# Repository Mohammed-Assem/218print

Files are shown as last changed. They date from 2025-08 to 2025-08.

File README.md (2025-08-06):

## 218print

218print is a simple bedslinger 3d printer designed to be as cheap as possible. I wanted to do this project because I don't know about 3d printers and I hoped to have one, so it was like a challenge to build it. I used3d printed parts in the motion of z-axis to be cheaper than universal plates.

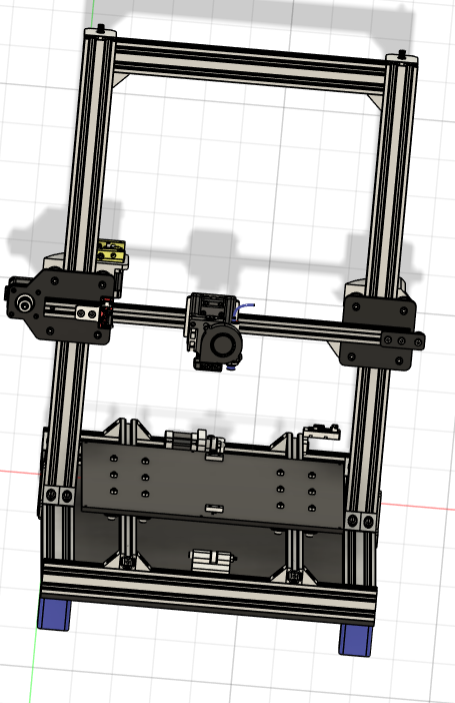
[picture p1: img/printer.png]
3D desgin
  
  z_axis
  y_axis

  this is my BOM file: 
  https://docs.google.com/spreadsheets/d/1YMHhHpfrs8DgpCIIZugQnNaR5hrPWCmoNuoNPDEoR1U/edit?usp=sharing

# Bill of Materials (BOM)

| Qty | Component | Price (EGP) | Total Price | Price (USD) | Link |
|-----|---|---|---|---|---|
| 1 | BIGTREETECH SKR MINI E3 V3.0 32 Bit Control Board | 3300 | 3300 | 68.04 | [Link](https://fluxelectronix.com/shop/bigtreetech-skr-mini-e3-v3-0-32-bit-control-board/) |
| 1 | Proximity Sensor - LJ12A3-4-Z-BX | £120.00 | £120.00 | 2.47 | [Link](https://lancer3d.com/product/proximity-sensor-lj12a3-4-z-bx/) |
| 2 | Mechanical End Stop Module | £25.00 | £50.00 | 1.03 | [Link](https://www.ram-e-shop.com/shop/kit-3d-1003-3d-printer-mechanical-end-stop-switch-module-for-ramps-sku-3d1003-7267) |
| 2 | Fan 4040 -- 24v | £35.00 | £70.00 | 1.44 | [Link](https://lancer3d.com/product/fan-4040-12v/) |
| 1 | 5015 Blower Fan -- 24v | £60.00 | £60.00 | 1.24 | [Link](https://lancer3d.com/product/5015-turbo-blower-fan-24-v-50x50x15mm/) |
| 1 | E3d V6 Hotend Full Kit | £325.00 | £325.00 | 6.70 | [Link](https://fluxelectronix.com/shop/e3d-v6-j-head-hotend-1-75mm-extruder-nozzle-0-4mm) |
| 1 | 214x214 3mm Aluminium | 290 | 290 | 5.98 | [Link](https://fluxelectronix.com/shop/3d-printer-mk3-aluminum-heatbed-214x214x3mm-dual-supply/) |
| 1 | Power Supply SMPS 20A 24V | £1,250.00 | £1,250.00 | 25.77 | [Link](https://fluxelectronix.com/shop/power-supply-smps-480w-24v-20a-hq/) |
| 1 | AC Inlet Power Socket with Fuse Holder | £15.00 | £15.00 | 0.31 | [Link](https://fluxelectronix.com/shop/panel-mount-ac-inlet-power-socket-with-fuse/) |
| 1 | Power Supply Cable | £30.00 | £30.00 | 0.62 | [Link](https://fluxelectronix.com/shop/ac-power-cord-with-iec-c13-connector/) |
| 1 | Zip Ties (100 pcs) | - | - | 0 | Already owned |
| 1 | NTC 100K Ohm Thermistor | £30.00 | £30.00 | 0.62 | [Link](https://fluxelectronix.com/shop/100k-ohm-ntc-thermistors-temperature-sensor-with-cable-for-3d-printer-2pin-dupont-head/) |
| 1 | 32GB Micro SD Memory Card HC10 | 375 | 375 | 7.73 | [Link](https://www.ram-e-shop.com/ar/shop/micro-sd-32gb-krt-mymwry-mykrw-32-jyj-hc10-6298) |
| 1 | Raspberry Pi Zero 2 W | 2100 | 2100 | 43.30 | [Link](https://www.ram-e-shop.com/ar/shop/raspberry-pi-zero-2w-raspberry-pi-zero-2-w-9256) |
| - | Mechanical | - | - | 0 | - |
| 5 | 2040 V-slot (34cm) | 300 | £1,500.00 | 30.93 | [Link](https://fluxelectronix.com/shop/2040-v-slot-aluminum-profile-extrusion-1m-black-anodized/) |
| 2 | 2040 V-slot (42cm) | - | - | 0 | - |
| 1 | 2040 V-slot (64cm) | - | - | 0 | - |
| 2 | 2040 V-slot (60cm) | - | - | 0 | - |
| 2.5 | 2020 V-slot (46cm) | 160 | £400.00 | 8.25 | [Link](https://www.juthour-tech.com/en/v-slot-20x20-linear-rail) |
| 1 | 2020 V-slot (68cm) | - | - | 0 | - |
| 22 | 2040 Corner Bracket | 20 | £440.00 | 9.07 | [Link](https://lancer3d.com/product/corner-bracket-for-20x40/) |
| 4 | Steel Flat T-Joint Plate | 25 | £100.00 | 2.06 | [Link](https://lancer3d.com/product/t-corner-mount-bracket/) |
| 2 | Corner Bracket 20x20 | 15 | £30.00 | 0.62 | [Link](https://lancer3d.com/product/corner-angle-20x20/) |
| 23 | Solid V-Wheel | 45 | £1,035.00 | 21.34 | [Link](https://fluxelectronix.com/shop/delrin-v-wheel/) |
| 3 | GT2 Timing Belt (X-axis, 1.5m) | 45 | £135.00 | 2.78 | [Link](https://ampere-electronics.com/product/gt2-open-belt-6mm-wide-pu-with-steel-core-1-meter-black/) |
| 1 | GT2 Timing Belt (Y-axis, 1.5m) | - | - | 0 | - |
| 90 | M5 Slide T-Nuts | 3.5 | £315.00 | 6.49 | [Link](https://ampere-electronics.com/product/m5-sliding-tee-nut-for-2020-profile/) |
| 2 | GT2 Pulley 20T 5mm | 30 | £60.00 | 1.24 | [Link](https://fluxelectronix.com/shop/20teeth-gt2-timing-belt-pulley-5mm-bore/) |
| 3 | GT2 Toothless Pulley 5mm | 35 | £105.00 | 2.16 | [Link](https://fluxelectronix.com/shop/toothless-gt2-idler-pulley-5mm-bore/) |
| 4 | Leveling Screw (M3x40) | 12.5 | £50.00 | 1.03 | [Link](https://ampere-electronics.com/product/leveling-kit-m3-screw-spring-knob-for-3d-printer/) |
| 5 | Nema17 Stepper Motor 17HS4401S – 38mm | £450.00 | £2,250.00 | 46.39 | [Link](https://fluxelectronix.com/shop/nema17-stepper-motor-17hs4401s-38mm/) |
| 1 | MK8 Remote Extruder Kit | 105 | £105.00 | 2.16 | [Link](https://ampere-electronics.com/product/mk8-remote-extruder-aluminum-frame-clamp-block-diy/) |
| 2 | Flexible Coupler 5x8mm | 40 | £80.00 | 1.65 | [Link](https://ampere-electronics.com/product/5x8mm-flexible-shaft-coupler/) |
| 1 | TR8x8 Lead Screw – 1200mm | 310 | £310.00 | 6.39 | [Link](https://ampere-electronics.com/product/tr8x8-acme-lead-screw-1200mm/) |
| 2 | TR8x8 Lead Screw Copper Nut | 30 | £60.00 | 1.24 | [Link](https://fluxelectronix.com/shop/tr8x8-acme-leadscrew-copper-nut/) |
| 10 | M5 Drop-in T-Nut | 3 | £30.00 | 0.62 | [Link](https://ampere-electronics.com/product/m5-drop-in-tee-nut-for-2020-aluminum-profile/) |
| 1 | M3x10mm Screw | - | - | 0 | Already owned |
| 1 | M3x15mm Screw | - | - | 0 | Already owned |
| 1 | M3x20mm Screw | - | - | 0 | Already owned |
| 1 | M3x25mm Screw | - | - | 0 | Already owned |
| 1 | M3 Standard Nut | - | - | 0 | Already owned |
| 1 | M5 Flat Head Screw 10mm | - | - | 0 | Already owned |
| 1 | M5 Flat Head Screw 12mm–15mm | - | - | 0 | Already owned |
| 1 | M5 Flat Head Screw 25mm | - | - | 0 | Already owned |
| 1 | M5 Flat Head Screw 30mm | - | - | 0 | Already owned |
| 1 | M5 Flat Head Screw 35mm | - | - | 0 | Already owned |
| 1 | M5 Flat Head Screw 40mm | - | - | 0 | Already owned |
| 12 | 6mm M5 Eccentric Spacer | 5 | £60.00 | 1.24 | [Link](https://ampere-electronics.com/product/aluminum-spacer-5-1x10x6mm/) |
| 10 | 3mm M5 Spacer | 3 | £30.00 | 0.62 | [Link](https://ampere-electronics.com/product/aluminum-spacer-5-1x10x3mm/) |
| 2 | 6mm M5 Spacer | 5 | £10.00 | 0.21 | [Link](https://ampere-electronics.com/product/aluminum-spacer-5-1x10x6mm/) |
| 20 | 9mm M5 Spacer | 7 | £140.00 | 2.89 | [Link](https://ampere-electronics.com/product/aluminum-spacer-5-1x10x9mm/) |
| 350g | 3D Printing Filament (EGP 4/g) | 3 | £1,050.00 | 21.65 | Will print in Flux |
| 1 | 1/4 Acrylic Sheet(0.5 m square) | 650 | £650.00 | 13.40 | - |

---

**Total Price:**  
- **EGP:** 10,257  
- **Total EGP:** £16,960.00  
- **USD:** $349.69

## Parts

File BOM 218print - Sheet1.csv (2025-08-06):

Quantity | Component | Price(EGP) | Total Price | price in usd | links local
1 | BIGTREETECH SKR MINI E3 V3.0 32 Bit Control Board | 3300 | 3300 | 68.04123711 | https://fluxelectronix.com/shop/bigtreetech-skr-mini-e3-v3-0-32-bit-control-board/
1 | Proximity-Sensor- LJ12A3-4-Z-BX | £120.00 | £120.00 | 2.474226804 | https://lancer3d.com/product/proximity-sensor-lj12a3-4-z-bx/
2 | Mechincal End Stop Module | £25.00 | £50.00 | 1.030927835 | https://www.ram-e-shop.com/shop/kit-3d-1003-3d-printer-mechanical-end-stop-switch-module-for-ramps-sku-3d1003-7267
2 | Fan 4040 -- 24v | £35.00 | £70.00 | 1.443298969 | https://lancer3d.com/product/fan-4040-12v/
1 | 5015 Blower fan -- 24v | £60.00 | £60.00 | 1.237113402 | https://lancer3d.com/product/5015-turbo-blower-fan-24-v-50x50x15mm/
1 | E3d V6 Hotend full kit | £325.00 | £325.00 | 6.701030928 | https://fluxelectronix.com/shop/e3d-v6-j-head-hotend-1-75mm-extruder-nozzle-0-4mm
1 | 300x300mm Silicone Heatbed, 220Vac, 600W | 290 | 290 | 5.979381443 | https://fluxelectronix.com/shop/3d-printer-mk3-aluminum-heatbed-214x214x3mm-dual-supply/
1 | Power Supply SMPS 20A 24V | £1,250.00 | £1,250.00 | 25.77319588 | https://fluxelectronix.com/shop/power-supply-smps-480w-24v-20a-hq/
1 | AC Inlet power socket with fuse holder | £15.00 | £15.00 | 0.3092783505 | https://fluxelectronix.com/shop/panel-mount-ac-inlet-power-socket-with-fuse/
1 | Power Supply cable | £30.00 | £30.00 | 0.618556701 | https://fluxelectronix.com/shop/ac-power-cord-with-iec-c13-connector/
1 | zip ties 100 |  |  | 0 | already owned
1 | NTC 100K ohm thermistor for heated bed | £30.00 | £30.00 | 0.618556701 | https://fluxelectronix.com/shop/100k-ohm-ntc-thermistors-temperature-sensor-with-cable-for-3d-printer-2pin-dupont-head/
1 | 32GB Micro SD Memory Card HC10 | 375 | 375 | 7.731958763 | https://www.ram-e-shop.com/ar/shop/micro-sd-32gb-krt-mymwry-mykrw-32-jyj-hc10-6298
1 | Raspberry Pi Zero 2 W | 2100 | 2100 | 43.29896907 | https://www.ram-e-shop.com/ar/shop/raspberry-pi-zero-2w-raspberry-pi-zero-2-w-9256
 | mechanical |  |  | 0
5 | 2040 V-slot aluminium profile 34cm (Frame) | 300 | £1,500.00 | £30.93 | https://fluxelectronix.com/shop/2040-v-slot-aluminum-profile-extrusion-1m-black-anodized/
 | 2 X 2040 V-slot aluminium profile 42cm (Frame) |  |  | 0
 | 1 X 2040 V-slot aluminium profile 64cm (Frame) |  |  | 0
 | 2 X 2040 V-slot aluminium profile 60cm (Frame) |  |  | 0
2.5 | 2020 V-slot aluminium profile 46cm (X-axis) | 160 | £400.00 | £8.25 | https://www.juthour-tech.com/en/v-slot-20x20-linear-rail
 | 2020 V-slot aluminium profile 68cm (Y-axis) |  |  | 0
22 | 2040 aluminum profile corner bracket | 20 | £440.00 | £9.07 | https://lancer3d.com/product/corner-bracket-for-20x40/
4 | Steel flat T-joint plate | 25 | £100.00 | £2.06 | https://lancer3d.com/product/t-corner-mount-bracket/
2 | corner bracket 20X20 | 15 | £30.00 | £0.62 | https://lancer3d.com/product/corner-angle-20x20/
23 | Solid V-wheel | 45 | £1,035.00 | £21.34 | https://fluxelectronix.com/shop/delrin-v-wheel/
3 | GT2 open timing 6mm belt for the X-axis (1.5 metre) | 45 | £135.00 | £2.78 | https://ampere-electronics.com/product/gt2-open-belt-6mm-wide-pu-with-steel-core-1-meter-black/
 | GT2 open timing 6mm belt for the Y-axis (1.5 metre) |  |  | 0
90 | M5 slide T_nuts | 3.5 | £315.00 | £6.49 | https://ampere-electronics.com/product/m5-sliding-tee-nut-for-2020-profile/
2 | GT2 20Teeth pulley for 6mm belt bore 5mm (5mm inner) | 30 | £60.00 | £1.24 | https://fluxelectronix.com/shop/20teeth-gt2-timing-belt-pulley-5mm-bore/
3 | GT2 Toothless pulley for 6mm belt bore 5mm (5mm inner) | 35 | £105.00 | £2.16 | https://fluxelectronix.com/shop/toothless-gt2-idler-pulley-5mm-bore/
4 | Leveling Screw (M3*40) | 12.5 | £50.00 | £1.03 | https://ampere-electronics.com/product/leveling-kit-m3-screw-spring-knob-for-3d-printer/
5 | Nema17 Stepper Motor 17HS4401S – 38mm | £450.00 | £2,250.00 | 46.39175258 | https://fluxelectronix.com/shop/nema17-stepper-motor-17hs4401s-38mm/
1 | MK8 Remote Extruder Kit | 105 | £105.00 | £2.16 | https://ampere-electronics.com/product/mk8-remote-extruder-aluminum-frame-clamp-block-diy/
2 | Flexible Coupler 5*8mm | 40 | £80.00 | £1.65 | https://ampere-electronics.com/product/5x8mm-flexible-shaft-coupler/
1 | TR8x8 Acme Lead Screw– 1200mm | 310 | £310.00 | £6.39 | https://ampere-electronics.com/product/tr8x8-acme-lead-screw-1200mm/
2 | TR8x8 Acme Leadscrew Copper Nut | 30 | £60.00 | £1.24 | https://fluxelectronix.com/shop/tr8x8-acme-leadscrew-copper-nut/
10 | M5 drop in T_nut | 3 | £30.00 | £0.62 | https://ampere-electronics.com/product/m5-drop-in-tee-nut-for-2020-aluminum-profile/
1 | M3x10mm screw |  |  | 0 | Already owned
1 | M3x15mm screw |  |  | 0
1 | M3 20mm screw |  |  | 0
1 | M3 25mm screw |  |  | 0
1 | M3 standard nut |  |  | 0
1 | M5--10mm flat head screw low profile |  |  | 0
1 | M5--12mm or 15mm flat head screw low profile |  |  | 0
1 | M5--25mm flat head screw low profile |  |  | 0
1 | M5--30mm flat head screw low profile |  |  | 0
1 | M5--35mm flat head screw low profile |  |  | 0
1 | M5--40mm flat head screw low profile |  |  | 0
12 | 6mm M5 Ecentric spacer for V-wheels | 5 | £60.00 | £1.24 | https://ampere-electronics.com/product/aluminum-spacer-5-1x10x6mm/
10 | 3mm M5 spacer | 3 | £30.00 | £0.62 | https://ampere-electronics.com/product/aluminum-spacer-5-1x10x3mm/
2 | 6mm M5 spacer | 5 | £10.00 | £0.21 | https://ampere-electronics.com/product/aluminum-spacer-5-1x10x6mm/
20 | 9mm M5 spacer | 7 | £140.00 | £2.89 | https://ampere-electronics.com/product/aluminum-spacer-5-1x10x9mm/
350 | 3d printing the gram of printing costs 4 EGP | 3 | £1,050.00 | £21.65 | I will print in flux electronics
1 | 1/4 acrlyic sheet | 650 | £650.00 | £13.40
total |  | 10257 | £16,960.00 | 349.6907216

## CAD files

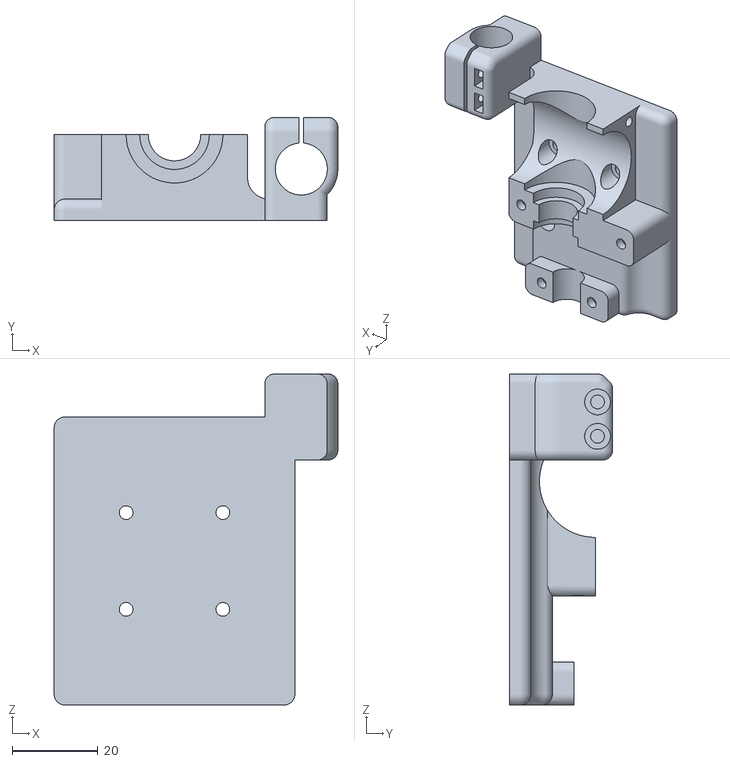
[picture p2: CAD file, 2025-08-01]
3D printed parts/STLs/Main_body_12mm_sensor.stl
66.0 x 24.0 x 77.0

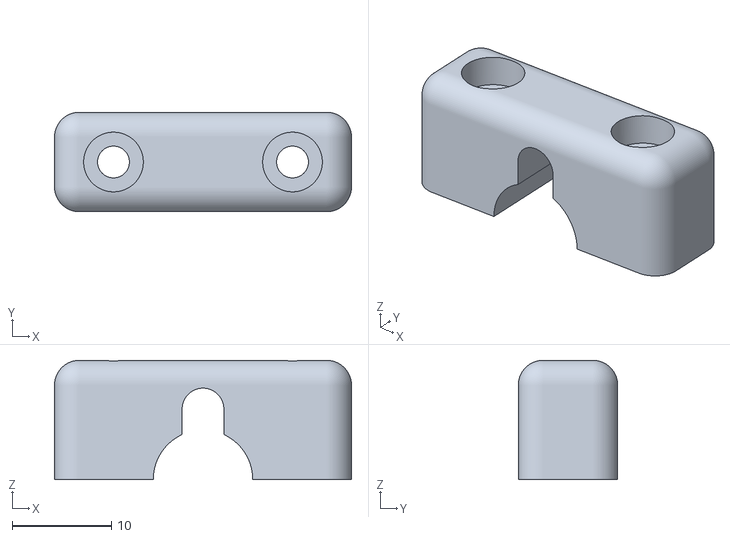
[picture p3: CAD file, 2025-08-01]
3D printed parts/STLs/Cable_clamp.stl
29.9 x 10.0 x 12.0

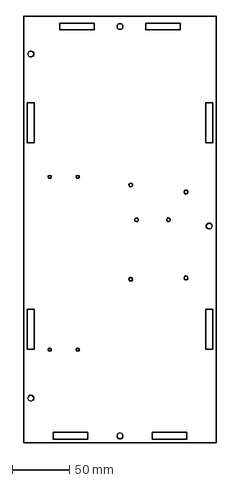
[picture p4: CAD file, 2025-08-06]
Acrylic sheets cut parts/DXFs/electronics base plate.dxf
168.0 x 373.1 mm

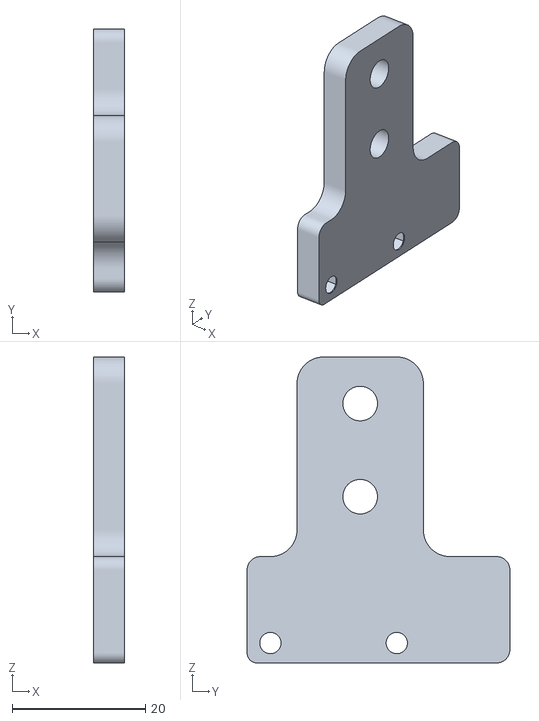
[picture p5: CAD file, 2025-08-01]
3D printed parts/STLs/X-axis endstop holder.stl
4.70 x 39.5 x 46.0

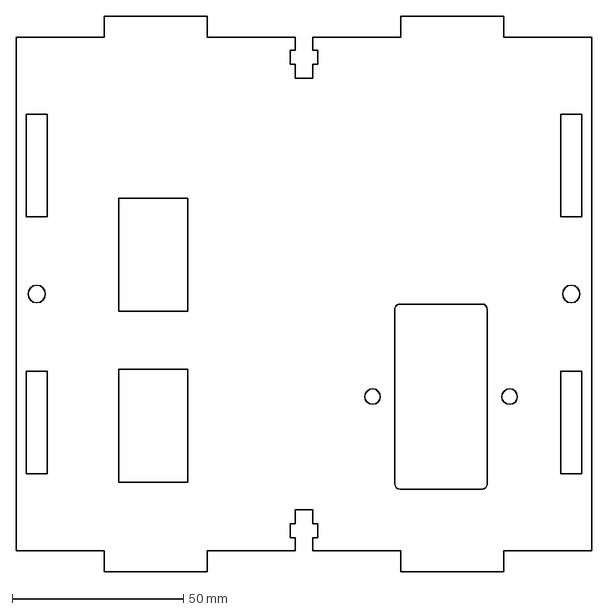
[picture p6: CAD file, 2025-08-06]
Acrylic sheets cut parts/DXFs/electronics back plate.dxf
168.0 x 162.0 mm

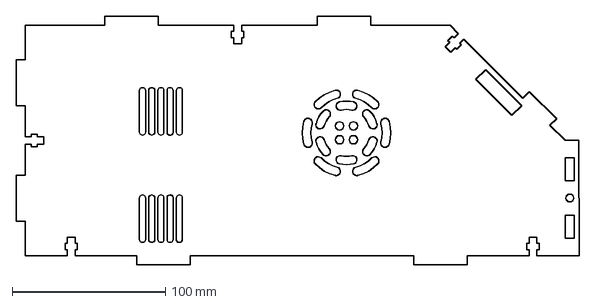
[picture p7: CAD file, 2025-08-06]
Acrylic sheets cut parts/DXFs/electronics left PSU plate.dxf
367.1 x 162.0 mm

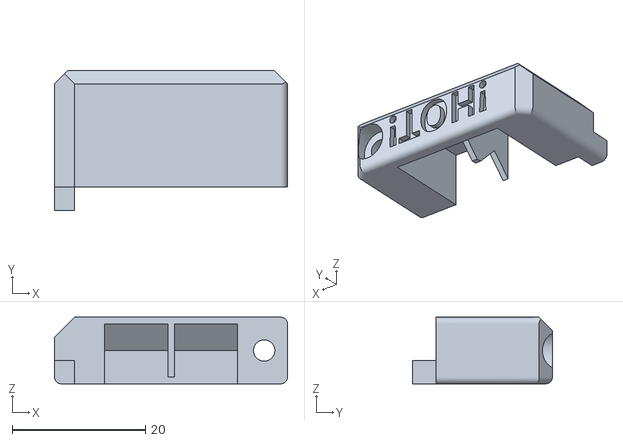
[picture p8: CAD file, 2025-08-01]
3D printed parts/STLs/Fan_duct v1.stl
35.0 x 21.0 x 10.0

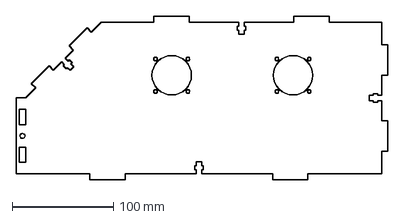
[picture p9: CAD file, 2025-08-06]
Acrylic sheets cut parts/DXFs/electronics right fans plate.dxf
367.1 x 162.0 mm

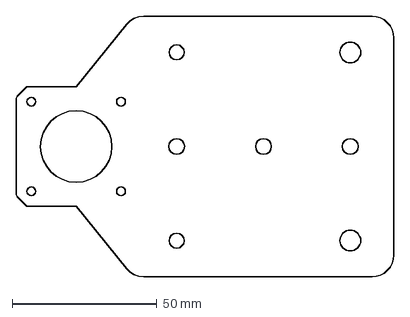
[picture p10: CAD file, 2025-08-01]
Acrylic sheets cut parts/DXFs/X-axis motor left plate.dxf
130.4 x 90.0 mm

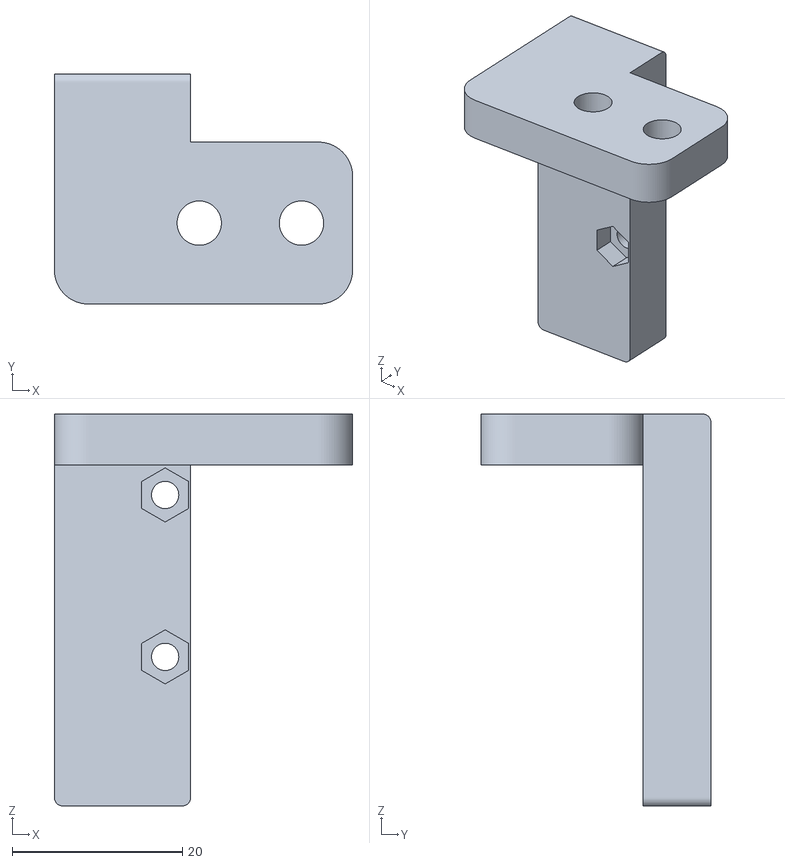
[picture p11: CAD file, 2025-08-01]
3D printed parts/STLs/Y-axis endstop holder.stl
35.0 x 27.0 x 46.0

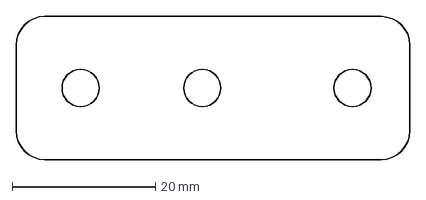
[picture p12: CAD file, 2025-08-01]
Acrylic sheets cut parts/DXFs/X-axis idler pulley plate.dxf
55.0 x 20.0 mm

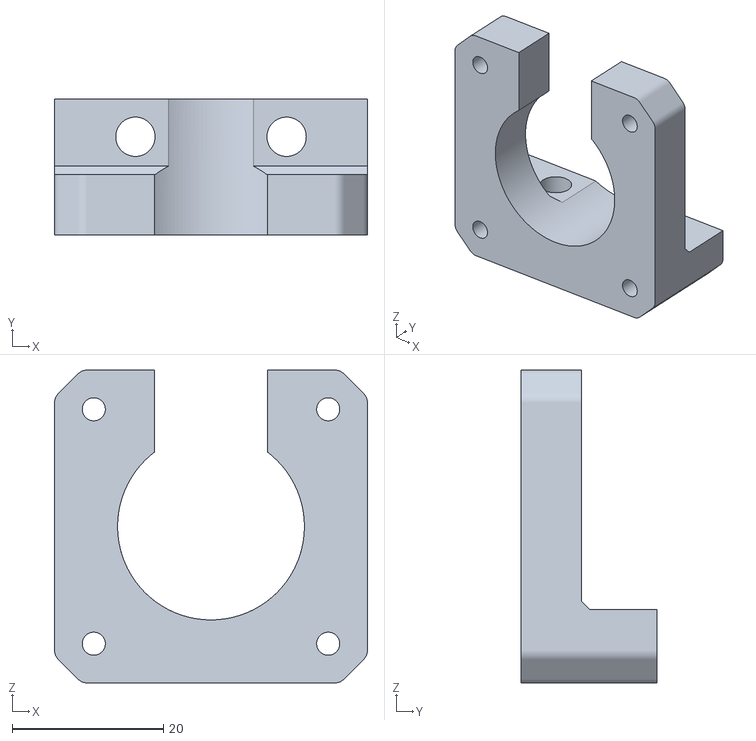
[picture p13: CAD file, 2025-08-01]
3D printed parts/STLs/Z_motor_bracket(Mirror).stl
41.4 x 18.0 x 41.4

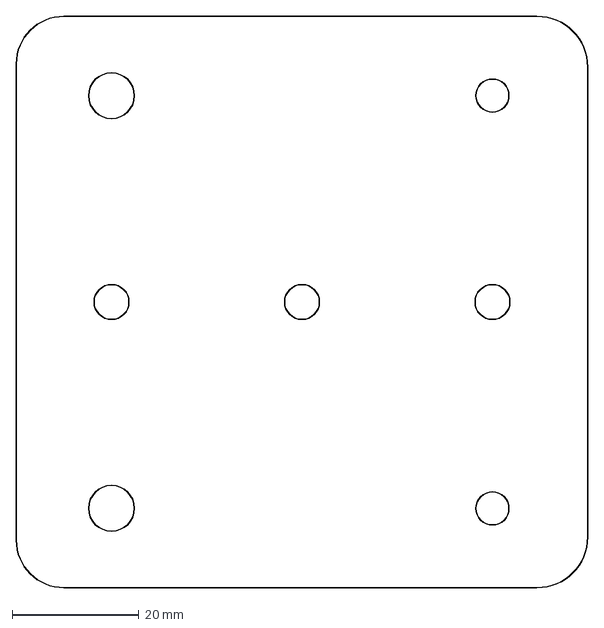
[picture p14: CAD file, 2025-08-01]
Acrylic sheets cut parts/DXFs/X-axis right plate.dxf
90.0 x 90.0 mm

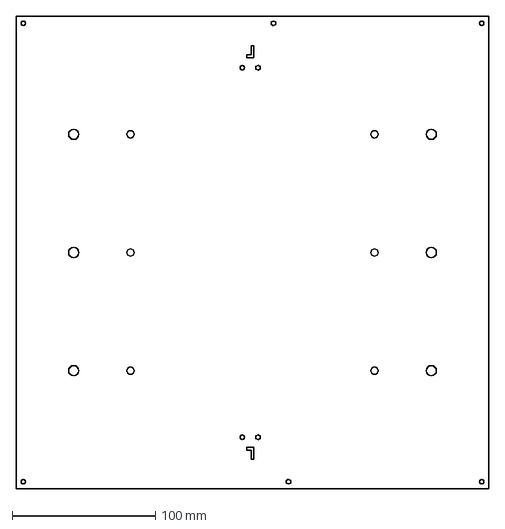
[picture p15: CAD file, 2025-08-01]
Acrylic sheets cut parts/DXFs/Heated bed carriage.dxf
330.0 x 330.0 mm

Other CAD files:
3D printed parts/STLs/2020 hot end plate.stl
Acrylic sheets cut parts/DXFs/Y-axis belt fixer.dxf
3D printed parts/STLs/Z_motor_bracket.stl
3D printed parts/STLs/Y-axis motor bracket (1).stl
3D printed parts/STLs/Hotend_clamp.stl
3D printed parts/STLs/Y-axis idler pulley holder.stl
3D printed parts/STLs/Z-axis extruder holder.stl
3D printed parts/STLs/Z-axis lead screw holder.stl
3D printed parts/STLs/lead screw support left.stl
3D printed parts/STLs/lead screw support right.stl

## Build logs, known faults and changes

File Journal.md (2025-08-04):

---
title: "218 Print"
author: "Mohamed Assem"
description: "Simple bedslinger 3D printer designed to be as cheap and precise as possible"
created_at: "2025-07-27"
---

### Total Time Spent: 19.5 Hours

---

## Journal

---

### 7/27/2025 — Introduction & Planning — Time Spent: 7 Hours  
As an introduction to both hardware and 3D printing, I began by exploring different 3D printer designs: Delta, CoreXY, and Bed Slinger. I chose the Bed Slinger for its simplicity, safety, and ease of construction — ideal for a first build.

My priorities were low cost and high accuracy, so I equipped all axes (X, Y, and Z) with V-slot rails, which offer both affordability and modularity. The Z-axis was driven vertically using a lead screw actuator for smooth, stable motion.

For the extruder, I selected a direct-drive X-carriage system paired with an E3D V6 Volcano hotend — both affordable and reliable. I also added a proximity sensor to enable automatic bed leveling.

- Print Size: 300 × 300 × 350 mm  
- Control Board: BIGTREETECH SKR MINI E3 V3.0  
  - Chosen for: documentation, cost, and Klipper compatibility  
- Estimated Total Cost: ~$325 USD

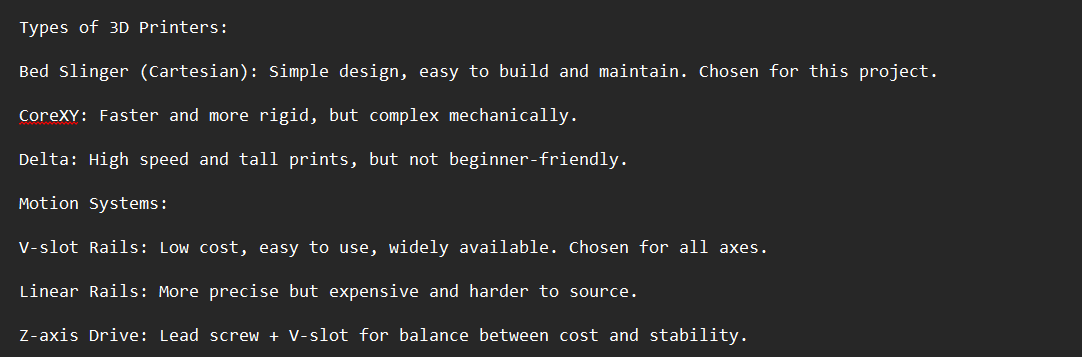
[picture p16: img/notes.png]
Part of Searching Notes


---

### 7/28/2025 — Frame Design in Fusion 360 — Time Spent: 3 Hours  
This was my first time using Fusion 360, so progress was initially slow. I designed the printer frame using 2040 aluminum V-slot extrusions for added rigidity, with final dimensions of 420 × 640 × 600 mm.

I used a combination of corner brackets and T-plates to reinforce joints, especially on the X-axis, which supports the frequently-moving print head.

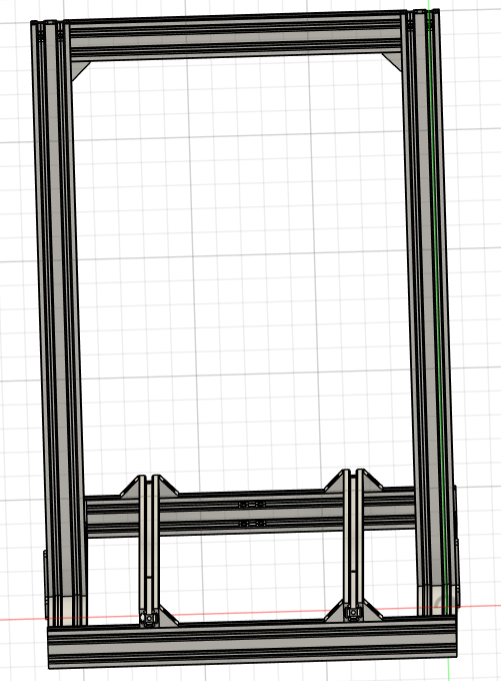
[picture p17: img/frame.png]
Frame


---

### 7/29/2025 — Mechanical Endstops & Bed Mount — Time Spent: 1 Hour  
I designed custom mechanical endstops triggered by the linear rail carriage — one for the X-axis (print head) and one for the Y-axis (bed).

Finding quality heated beds in Egypt was difficult and expensive, so I designed my own and used 4 mm acrylic sheets, CNC cut.

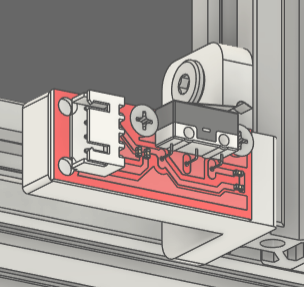
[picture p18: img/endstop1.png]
Endstop 1
  
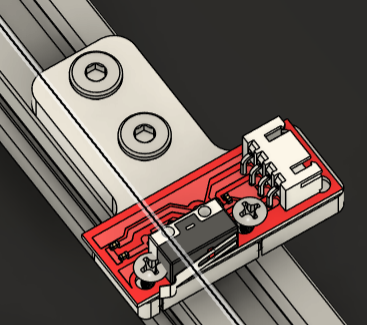
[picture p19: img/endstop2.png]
Endstop 2
  
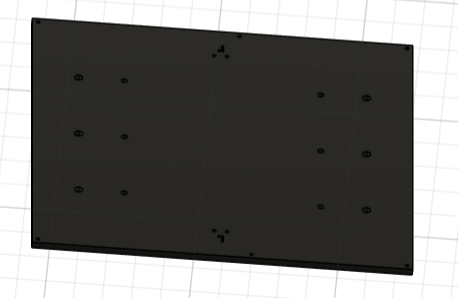
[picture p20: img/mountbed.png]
Mount Bed


---

### 7/30/2025 — Y-Axis Assembly — Time Spent: 2 Hours  
I completed the Y-axis and added 12 V-wheels to the bed mount, which is connected to a belt driven by a stepper motor. I also added spacers to support the frame and elevate the structure.

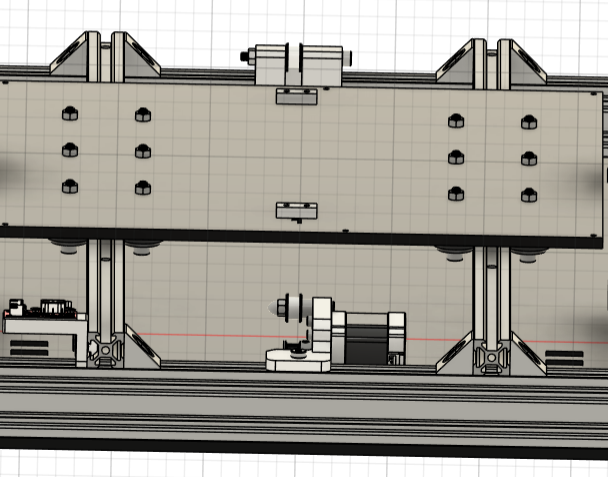
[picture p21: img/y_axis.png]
Y-Axis


---

### 7/31/2025 — Z-Axis & Structural Reinforcement — Time Spent: 4 Hours  
I completed the Z-axis design using custom 3D-printed plates instead of universal aluminum mounts, reducing both weight and cost.

The Z-axis uses a lead screw and V-slot rails, with proper alignment to minimize wobble. Despite supporting the relatively heavy print head, the design remains stable. One plate holds the endstop and stepper motor (which feeds filament), while the opposite side is purely for motion.

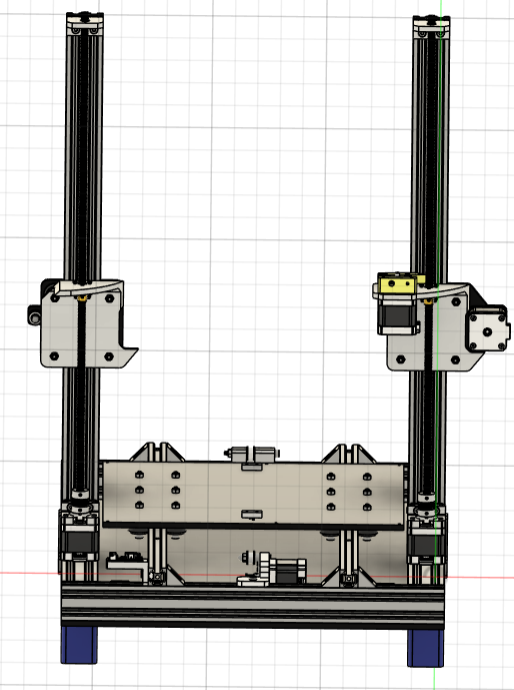
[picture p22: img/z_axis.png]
Z-Axis
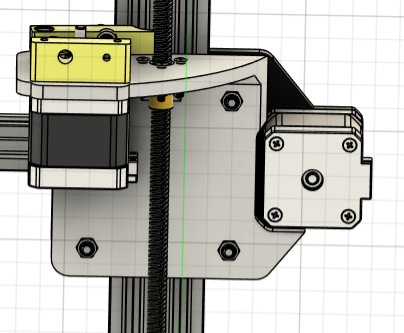
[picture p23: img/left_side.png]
Left Side
     
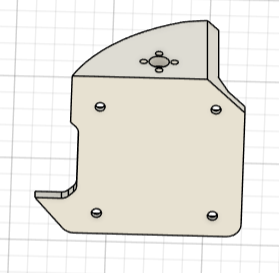
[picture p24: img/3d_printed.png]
3D Printed Parts
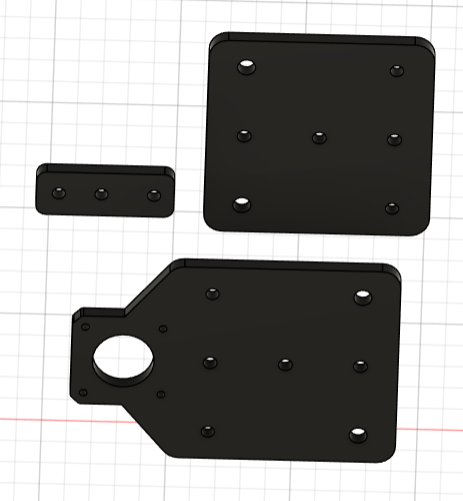
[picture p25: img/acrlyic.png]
Acrylic Parts
   

---

### 8/1/2025 — X-Axis & Print Head — Time Spent: 3 Hours  
I finalized the X-axis and print head assembly. The direct-drive extruder, Volcano hotend, and proximity sensor were mounted. I also added belt clamps and tensioners for the X-axis. Final adjustments ensured correct nozzle alignment with the print bed center.

I added a support beam connecting the top of the extrusion frame to increase rigidity and durability.

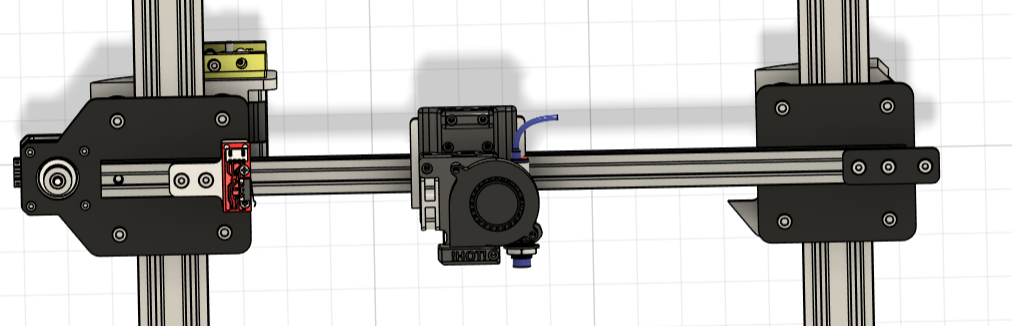
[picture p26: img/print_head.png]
Print Head
  
Final Printer
